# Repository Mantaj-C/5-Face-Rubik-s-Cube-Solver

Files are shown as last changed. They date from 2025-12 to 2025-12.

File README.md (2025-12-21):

# 🤖 Rubik’s Cube Solver – 5-Face Camera System
### 🔗 LinkedIn Post  
I also shared this project on LinkedIn — read the full post here:  
👉 [LinkedIn](https://www.linkedin.com/posts/mantaj-chauhan-951b401b5_just-completed-my-custom-5-face-rubik-activity-7408614489727696896-skUq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)

This project is a custom Rubik’s Cube solving machine, fully designed from scratch on the hardware, control logic, UI, and computer vision side, and powered by the well-known [rob-twophase](https://github.com/efrantar/rob-twophase) solving algorithm to improve my skills in:

- C++ software architecture  
- OpenCV computer vision  
- SolidWorks mechanical design  
- PCB design in Altium  
- Stepper motor control  
- TCP/IP networking  

The system uses a **client–server architecture**:

- 🍓 **Raspberry Pi → Client**  
  Handles motors, microstepping, camera capture, OpenCV color detection.

- 💻 **MacBook → Server**  
  Handles solving, graphical interface, 3D cube rendering, and control panel.

---

## 🎥 Demo Videos

**System Demo:**  
https://youtu.be/CzUOWeb3go8  

**SolidWorks Breakdown:**  
https://youtu.be/Gd5gCoYmTEs  

---

## 📂 Project Structure
```text
RubiksCubeSolver/
│
├── PCB Files/            # Custom PCB schematics + motor driver board
│
├── Solidworks Files/     # Full CAD of the solver mechanism
│
└── Src/
    ├── Client/           # Raspberry Pi: motor control + camera scanning
    └── Server/           # Mac: solver engine, UI, 3D viewer (SFML + OpenGL)
```

---

# 🏗 System Overview

## 💻 Server (Mac)
Responsible for:
- Running the [**rob-twophase**](https://github.com/efrantar/rob-twophase) solver  
- Managing the **SFML + OpenGL** graphical control panel  
- Rendering a **3D cube** with animations  
- Sending commands to the Pi  
- Parsing responses  
- Timing, batching moves, and UI updates  

Technologies used:
- C++20  
- SFML  
- OpenGL  
- TCP/IP sockets  

---

## 🍓 Client (Raspberry Pi)
Responsible for:
- Driving 6 stepper motors  
- Applying microstepping (Full → Sixteenth)  
- Handling acceleration & deceleration curves  
- Capturing images with OpenCV  
- Detecting colors with HSV processing  
- Validating cube color layout  
- Sending the final **54-character facelet string** to the server  

Technologies used:
- C++  
- OpenCV  
- pigpio  
- Multithreading  
- TCP/IP sockets  

---

# 🌐 TCP/IP Communication

The architecture uses a **simple text-based custom protocol** over TCP sockets.

## Server → Client Commands
```text
B M <face> <direction> <angle>;    # Rotate face
B F <freq>;                        # Set stepper frequency
B S;                               # Start sync (camera scan)
B T;                               # Start solve timer
Q                                  # Quit
```
## Client → Server Responses
```text
T <time_ms>          # Solve time in milliseconds
S <54-char-facelet>  # Camera-detected cube state
DONE                 # No special condition
```

---

# ⭐ Key Features

### 🖼 5-Face Camera Scanning
- Captures 13 images  
- Uses polygon masks to isolate facelets  
- Computes average HSV color  
- Maps HSV ranges → Rubik’s cube colors  
- Performs cube validity checks  

### ⚙️ Stepper Motor System
- Custom acceleration/deceleration curve  
- Shared microstepping modes  
- Ring-gear stepper for cube rotation  
- 5 turning steppers for each face  
- PWM + GPIO control via pigpio  

### 🧠 Solving Logic
- Uses [**rob-twophase**](https://github.com/efrantar/rob-twophase) solver  
- Converts solver moves → motor moves  
- Supports patterns, shuffles, syncing  

### 🖥 Graphical UI
- Built with **SFML + OpenGL**  
- Real-time visual cube  
- Move animations  
- Pattern selection  
- Manual motor controls  
- Timers & solve history  

### 🛠 Mechanical + PCB Design
- Entirely designed in SolidWorks  
- Custom PCB designed in Altium for stepper drivers  
- Gear system + mounting structure  
- Designed for stability, alignment, and lighting  

---

# 📘 What I Learned

This project helped me grow in:

- C++ class design, multithreading, and architecture  
- Real-time image processing with OpenCV  
- Hardware–software integration  
- Stepper motor tuning and microstepping  
- TCP/IP networking and protocol design  
- SFML & OpenGL graphics  
- SolidWorks mechanical design  
- Altium PCB layout and driver electronics  
- Full system debugging across multiple platforms  

This was one of my most complete end-to-end engineering builds, combining software, mechanical, electrical, and computer vision into a single cohesive system.

The solver is powered by the [rob-twophase] library.

[rob-twophase]: https://github.com/efrantar/rob-twophase

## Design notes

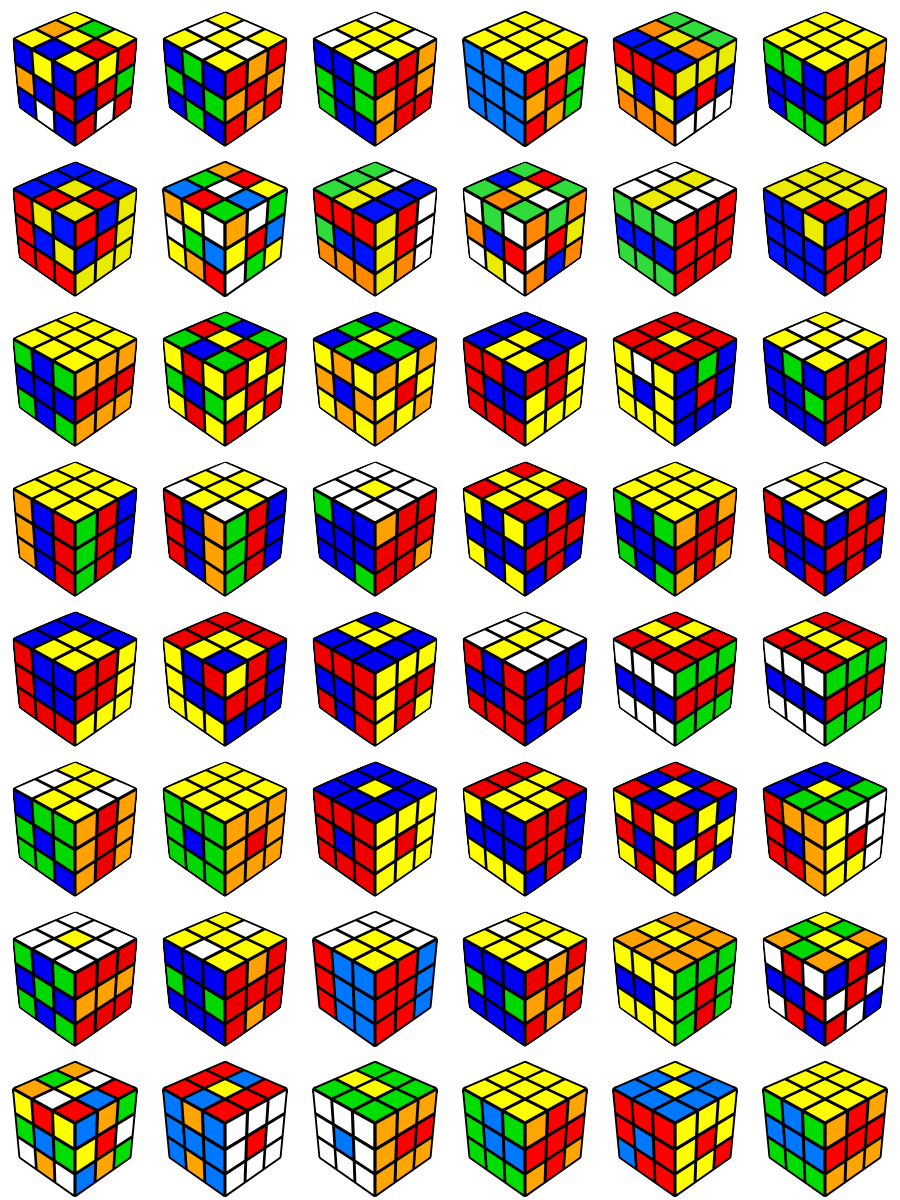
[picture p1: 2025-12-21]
Src/Client/Patterns_Sprite_Sheet.png

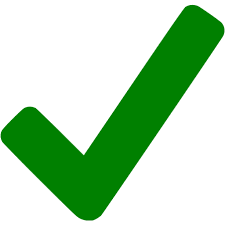
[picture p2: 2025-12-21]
Src/Client/check.png

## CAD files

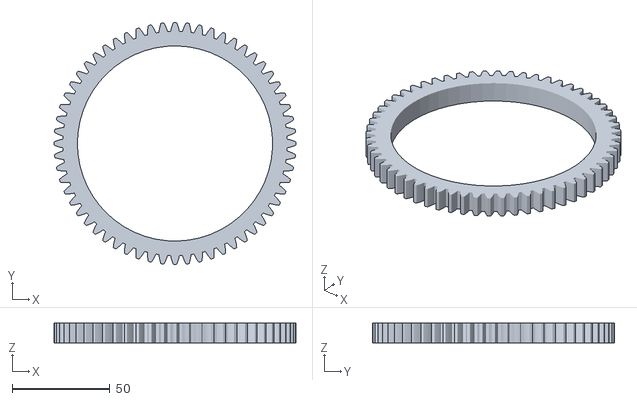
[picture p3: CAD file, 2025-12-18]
Solidworks Files/Ring_Gear.STL
124.0 x 124.0 x 10.0

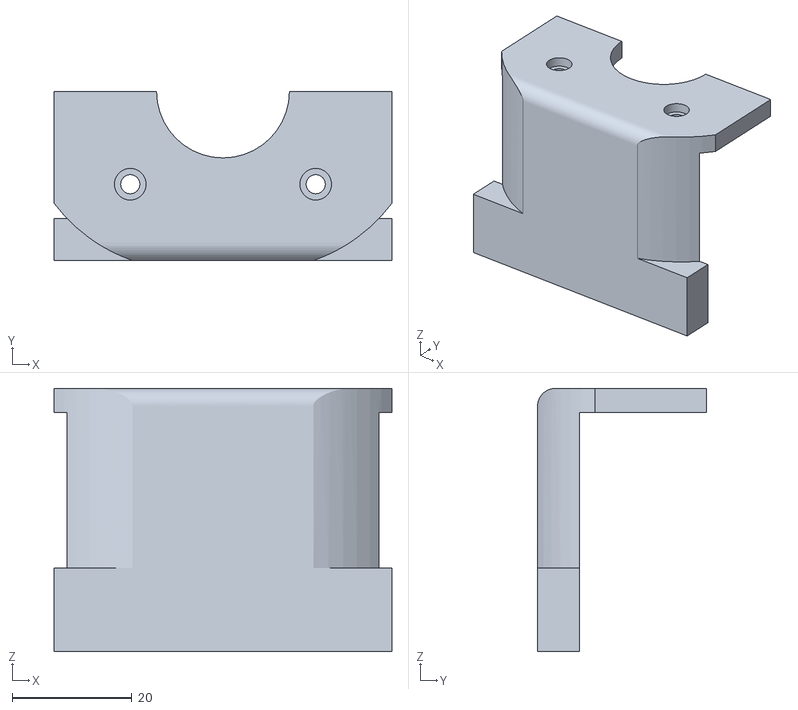
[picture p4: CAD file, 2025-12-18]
Solidworks Files/Middle_Stepper_Bracket.STL
56.5 x 28.2 x 44.0

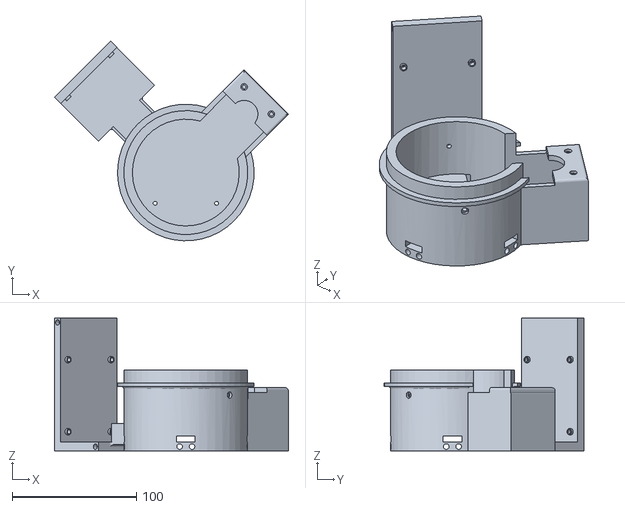
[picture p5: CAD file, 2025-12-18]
Solidworks Files/Base.STL
188.4 x 160.8 x 107.0

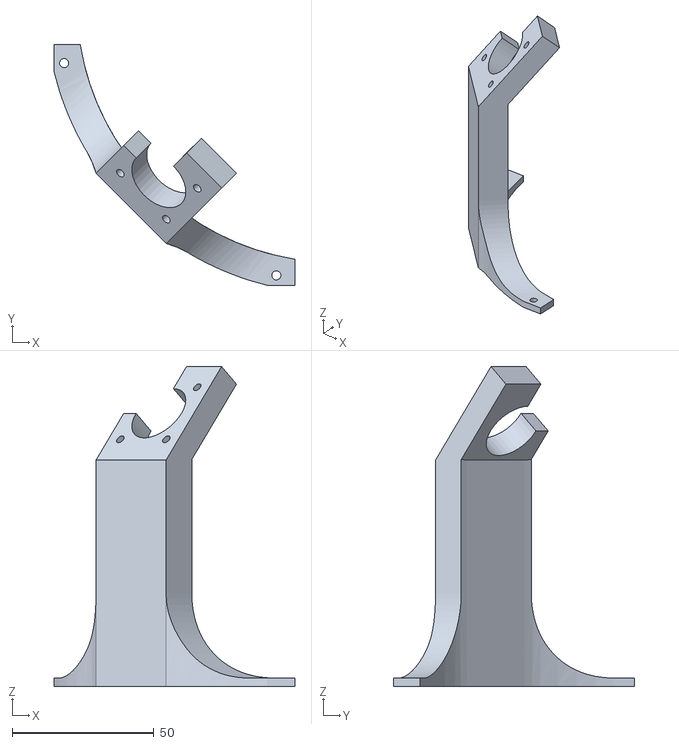
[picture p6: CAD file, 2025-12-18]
Solidworks Files/Camera_Mount.STL
85.0 x 85.0 x 113.1

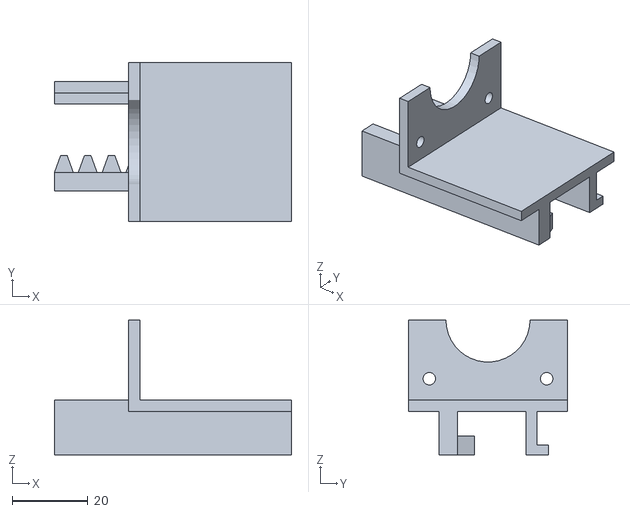
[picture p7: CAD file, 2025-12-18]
Solidworks Files/Stepper_Racks.STL
62.6 x 42.0 x 35.6

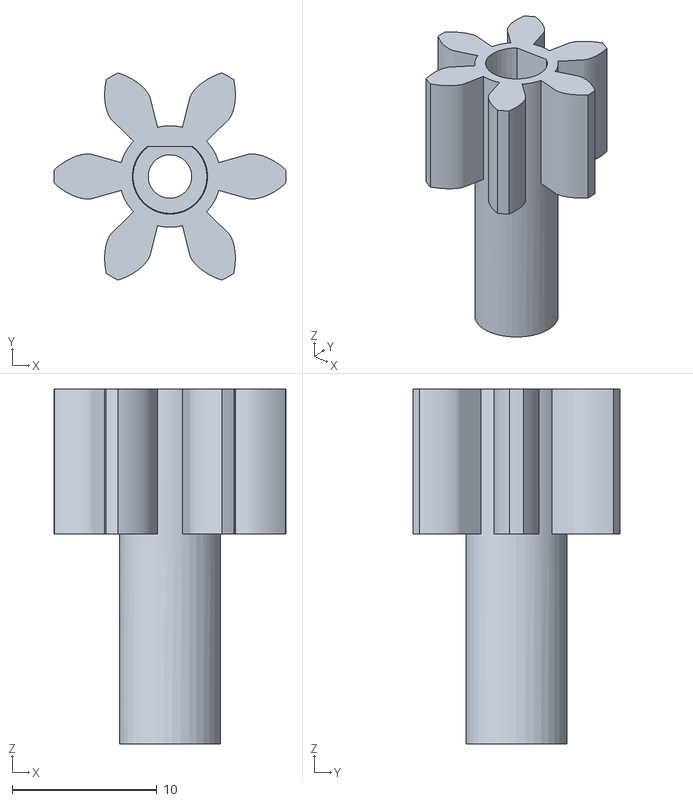
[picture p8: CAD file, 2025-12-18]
Solidworks Files/Stepper_Gear.STL
16.0 x 14.3 x 24.5

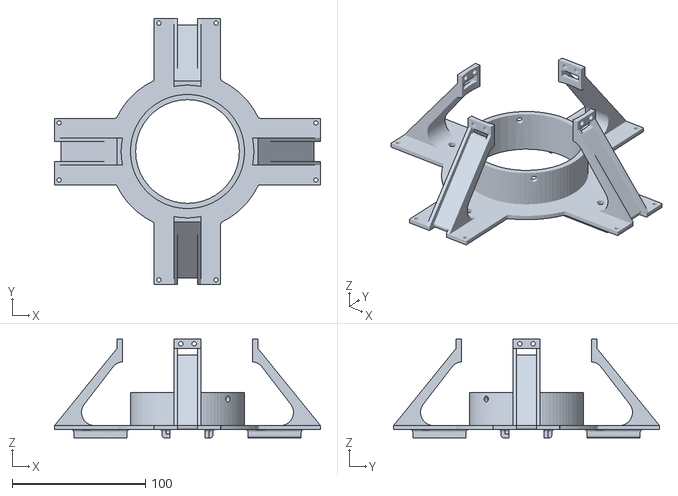
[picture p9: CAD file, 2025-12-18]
Solidworks Files/Upper_Level.STL
200.0 x 200.0 x 74.2

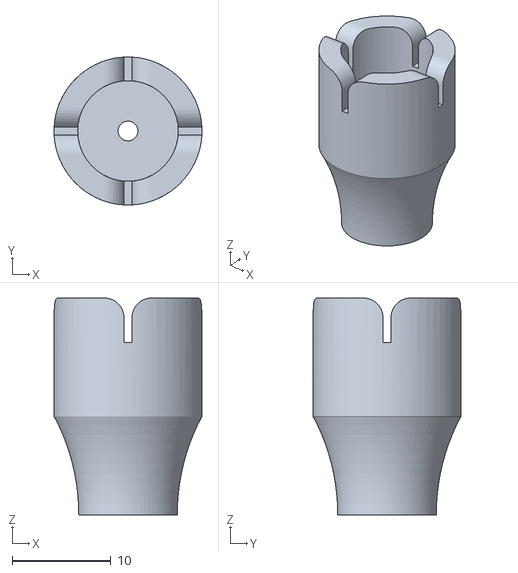
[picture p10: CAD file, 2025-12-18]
Solidworks Files/Stepper_To_Cube_Connection.STL
15.0 x 15.0 x 22.0

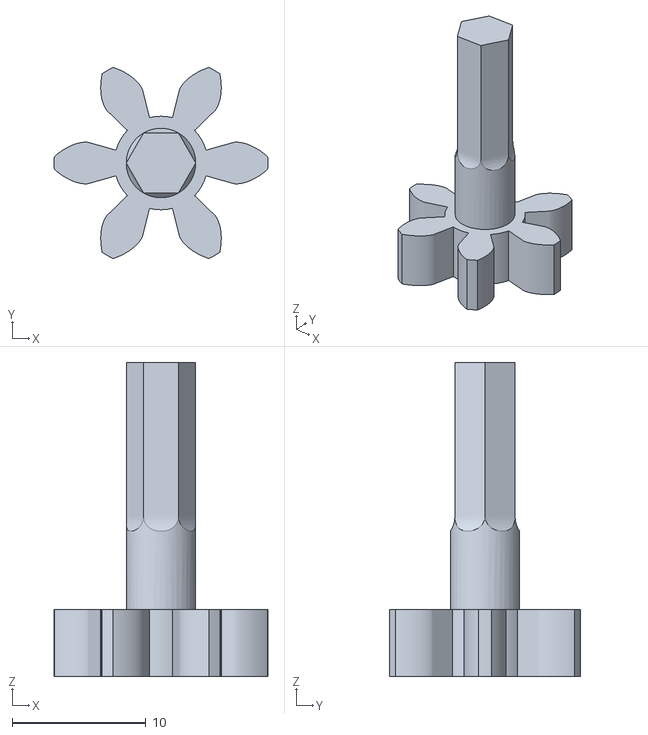
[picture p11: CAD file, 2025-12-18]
Solidworks Files/Ring_to_Stepper_Gear_1.STL
16.0 x 14.3 x 23.5

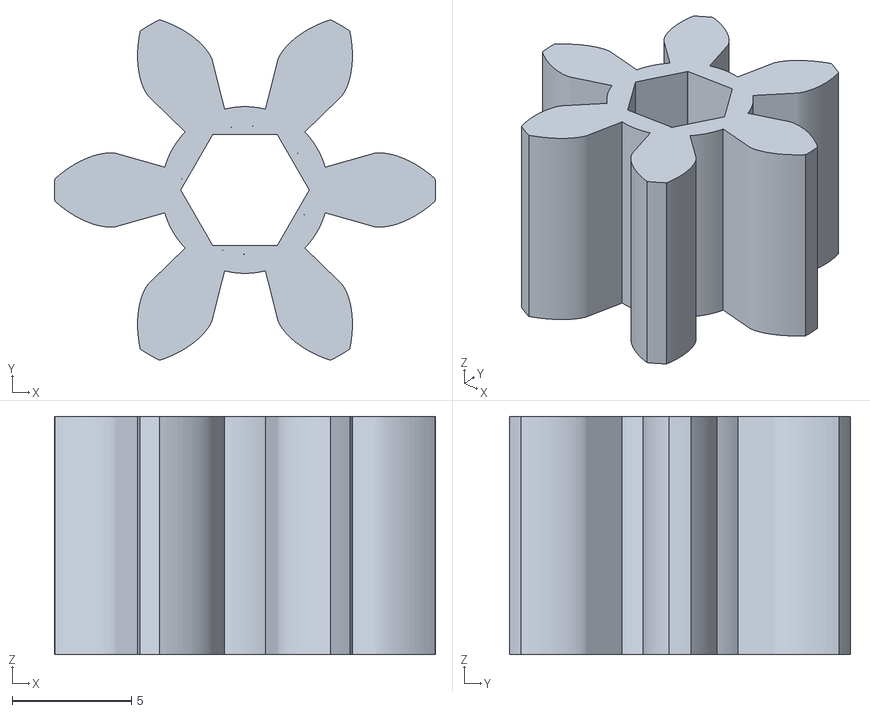
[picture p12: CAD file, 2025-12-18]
Solidworks Files/Ring_to_Stepper_Gear_2.STL
16.0 x 14.3 x 10.0

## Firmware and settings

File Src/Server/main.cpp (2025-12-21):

#include "GPIO.h"
#include "Stepper.h"
#include "Camera.h"
#include <arpa/inet.h>
#include <netinet/in.h>
#include <sys/socket.h>
#include <unistd.h>
#include <cstring>
#include <iostream>
#include <sstream>
#include <thread>
#include <vector>
#include <chrono>

// ---------------------- Pin Definitions ----------------------
// Ring gear stepper (locks/unlocks the cube clamp)
#define RING_Gear_Stepper_Enable_Pin     24
#define RING_Gear_Stepper_Direction_Pin  19
#define RING_Gear_Stepper_Step_Pin       26
#define RING_Gear_Stepper_MS1_Pin        25
#define RING_Gear_Stepper_MS2_Pin        8
#define RING_Gear_Stepper_MS3_Pin        7

// Shared microstepping pins for all turning steppers
#define Turning_Steppers_Enable_Pin      23
#define Turning_Steppers_MS1_Pin         16
#define Turning_Steppers_MS2_Pin         20
#define Turning_Steppers_MS3_Pin         21

// Individual face steppers (Bottom, North, East, South, West)
#define Bottom_Stepper_Direction_Pin     27
#define Bottom_Stepper_Step_Pin          22

#define North_Stepper_Direction_Pin      4
#define North_Stepper_Step_Pin           17

#define East_Stepper_Direction_Pin       9
#define East_Stepper_Step_Pin            10

#define South_Stepper_Direction_Pin      6
#define South_Stepper_Step_Pin           13

#define West_Stepper_Direction_Pin       11
#define West_Stepper_Step_Pin            5

// ------------------- Server / Motion Constants ----------------
#define DEFAULT_FREQUENCY 1350          // Default step pulse frequency (Hz)
#define PORT 5050                       // TCP port
#define BUFFER_SIZE 1024
#define RING_STEPPER_LOCK_DEGREES 800   // Steps for locking/unlocking clamp

// #define CAMERA_STREAM                 // Enable live camera preview
// #define NO_CLIENT_TESTING             // Enable local stdin command mode

int main() {
    // ---- Camera object ----
    Camera cam;

#ifdef CAMERA_STREAM
    // Optional: start asynchronous camera preview for calibration/debug
    std::thread t(std::bind(&Camera::getandshow, &cam));
    t.detach();
#endif

    int default_freq = DEFAULT_FREQUENCY;

    // Timer / sync state flags
    float solve_time = 0;
    bool timer_flag = false;
    bool sync_flag = false;
    bool valid_cube = true;

    auto start = std::chrono::high_resolution_clock::now();

    // Shared microstepping mode for all face steppers
    Stepper::StepMode sharedMode = Stepper::FULL;

    // ---------------------- Stepper Initialization ----------------------
    // Ring gear stepper (lock/unlock)
    Stepper Gear_Stepper(
        RING_Gear_Stepper_Enable_Pin,
        RING_Gear_Stepper_Direction_Pin,
        RING_Gear_Stepper_Step_Pin,
        RING_Gear_Stepper_MS1_Pin,
        RING_Gear_Stepper_MS2_Pin,
        RING_Gear_Stepper_MS3_Pin
    );

    // Face steppers (all share same enable + MS1/MS2/MS3)
    Stepper Bottom_Stepper(
        Turning_Steppers_Enable_Pin,
        Bottom_Stepper_Direction_Pin,
        Bottom_Stepper_Step_Pin,
        Turning_Steppers_MS1_Pin,
        Turning_Steppers_MS2_Pin,
        Turning_Steppers_MS3_Pin,
        &sharedMode
    );

    Stepper North_Stepper(
        Turning_Steppers_Enable_Pin,
        North_Stepper_Direction_Pin,
        North_Stepper_Step_Pin,
        Turning_Steppers_MS1_Pin,
        Turning_Steppers_MS2_Pin,
        Turning_Steppers_MS3_Pin,
        &sharedMode
    );

    Stepper East_Stepper(
        Turning_Steppers_Enable_Pin,
        East_Stepper_Direction_Pin,
        East_Stepper_Step_Pin,
        Turning_Steppers_MS1_Pin,
        Turning_Steppers_MS2_Pin,
        Turning_Steppers_MS3_Pin,
        &sharedMode
    );

    Stepper South_Stepper(
        Turning_Steppers_Enable_Pin,
        South_Stepper_Direction_Pin,
        South_Stepper_Step_Pin,
        Turning_Steppers_MS1_Pin,
        Turning_Steppers_MS2_Pin,
        Turning_Steppers_MS3_Pin,
        &sharedMode
    );

    Stepper West_Stepper(
        Turning_Steppers_Enable_Pin,
        West_Stepper_Direction_Pin,
        West_Stepper_Step_Pin,
        Turning_Steppers_MS1_Pin,
        Turning_Steppers_MS2_Pin,
        Turning_Steppers_MS3_Pin,
        &sharedMode
    );

    // Index mapping for "face" integer in commands (0..5)
    // 0=Bottom, 1=East, 2=North, 3=Gear, 4=West, 5=South
    std::vector<Stepper> steppers = {
        Bottom_Stepper,
        East_Stepper,
        North_Stepper,
        Gear_Stepper,
        West_Stepper,
        South_Stepper
    };

    // ---------------------- TCP Server Setup ----------------------
    int server_fd = socket(AF_INET, SOCK_STREAM, 0);
    if (server_fd == -1) {
        perror("Socket creation failed");
        return 1;
    }

    sockaddr_in address{};
    address.sin_family = AF_INET;
    address.sin_addr.s_addr = INADDR_ANY;   // Bind on all interfaces
    address.sin_port = htons(PORT);

    if (bind(server_fd, (struct sockaddr*)&address, sizeof(address)) < 0) {
        perror("Bind failed");
        return 1;
    }

    if (listen(server_fd, 3) < 0) {
        perror("Listen failed");
        return 1;
    }

    std::cout << "Raspberry Pi motor server listening on port " << PORT << "...\n";

    // ---------------------- Main Accept Loop ----------------------
    while (true) {
#ifndef NO_CLIENT_TESTING
        // Wait for a client connection (Mac UI)
        int client_fd = accept(server_fd, nullptr, nullptr);
        if (client_fd < 0) {
            perror("Accept failed");
            continue;
        }
#endif

#ifdef NO_CLIENT_TESTING
        // Testing mode: no socket, just stdin
        int client_fd = 0;
#endif

        // -------------- Per-Client Command Loop --------------
        while (true) {

#ifdef NO_CLIENT_TESTING
            // Testing mode: read command from terminal
            std::string command;
            std::cout << "Enter command: ";
            std::getline(std::cin, command);
#endif

#ifndef NO_CLIENT_TESTING
            // Normal mode: read command from TCP socket
            char buffer[BUFFER_SIZE] = {0};
            int bytes_read = read(client_fd, buffer, BUFFER_SIZE);
            if (bytes_read <= 0) break;   // client disconnected
            std::string command(buffer, bytes_read);
#endif

            std::ostringstream reply;
            std::cout << "Received command: " << command << std::endl;

            // ---------------- BATCH COMMAND MODE ("B ...") ----------------
            if (command[0] == 'B') {
                // After 'B', we expect semicolon-separated mini-commands
                std::string sub = command.substr(1);
                std::istringstream batch(sub);
                std::string token;

                while (std::getline(batch, token, ';')) {
                    std::istringstream cmd(token);
                    std::string keyword;
                    cmd >> keyword;

                    // ---- M = Move: "M face direction amount" ----
                    if (keyword == "M") {
                        int face, direction, amount;
                        cmd >> face >> direction >> amount;

                        if (face >= 0 && face < (int)steppers.size()) {
                            auto dir = (direction == 1)
                                ? Stepper::CLOCKWISE
                                : Stepper::COUNTER_CLOCKWISE;

                            steppers[face].rotate(amount, dir, default_freq);

                            std::cout << "Rotated " << amount
                                      << " steps on face " << face
                                      << " in direction " << direction << std::endl;
                            // Optional delay here if needed for camera stability
                            // std::this_thread::sleep_for(std::chrono::milliseconds(1000));
                        }

                    // ---- E = Enable: "E face" ----
                    } else if (keyword == "E") {
                        int face;
                        cmd >> face;
                        if (face >= 0 && face < (int)steppers.size()) {
                            steppers[face].enable();
                        }

                    // ---- D = Disable: "D face" ----
                    } else if (keyword == "D") {
                        int face;
                        cmd >> face;
                        if (face >= 0 && face < (int)steppers.size()) {
                            steppers[face].disable();
                        }

                    // ---- F = Set Frequency: "F freq" ----
                    } else if (keyword == "F") {
                        int freq;
                        cmd >> freq;
                        default_freq = freq;

                    // ---- T = Timer Start ----
                    // Mac expects a "T <ms>" response when solving completes.
                    } else if (keyword == "T") {
                        timer_flag = true;
                        start = std::chrono::high_resolution_clock::now();

                    // ---- MS = Microstepping: "MS<group> <mode>" ----
                    // Example: "MS0 4" → group 0 (ring), SIXTEENTH mode
                    } else if (token.substr(0, 2) == "MS") {
                        int group, mode;
                        std::istringstream ms_cmd(token.substr(2));
                        ms_cmd >> group >> mode;

                        Stepper::StepMode sm;
                        switch (mode) {
                            case 0: sm = Stepper::FULL;      break;
                            case 1: sm = Stepper::HALF;      break;
                            case 2: sm = Stepper::QUARTER;   break;
                            case 3: sm = Stepper::EIGHTH;    break;
                            case 4: sm = Stepper::SIXTEENTH; break;
                            default:
                                std::cerr << "Invalid step mode: " << mode << std::endl;
                                send(client_fd, "ERR\n", 4, 0);
                                continue;
                        }

                        // group 0 = Gear stepper, group 1 = other steppers
                        if (group == 0) Gear_Stepper.setMode(sm);
                        else Bottom_Stepper.setMode(sm);

                    // ---- S = Sync (Full cube scan + color recognition) ----
                    } else if (keyword == "S") {
                        // Only run once per command; valid_cube forces exit
                        while (valid_cube) {
                            cam.sync_reset();

                            // Capture 13 images with specific rotation sequence
                            cam.getimage(0);

                            North_Stepper.rotate(90, Stepper::CLOCKWISE, default_freq / 2);
                            cam.getimage(1);

                            North_Stepper.rotate(90, Stepper::CLOCKWISE, default_freq / 2);
                            cam.getimage(2);

                            North_Stepper.rotate(90, Stepper::CLOCKWISE, default_freq / 2);
                            cam.getimage(3);

                            North_Stepper.rotate(90, Stepper::CLOCKWISE, default_freq / 2);

                            West_Stepper.rotate(90, Stepper::CLOCKWISE, default_freq / 2);
                            cam.getimage(4);

                            West_Stepper.rotate(90, Stepper::CLOCKWISE, default_freq / 2);
                            cam.getimage(5);

                            West_Stepper.rotate(90, Stepper::CLOCKWISE, default_freq / 2);
                            cam.getimage(6);

                            West_Stepper.rotate(90, Stepper::CLOCKWISE, default_freq / 2);

                            South_Stepper.rotate(90, Stepper::CLOCKWISE, default_freq / 2);
                            West_Stepper.rotate(180, Stepper::CLOCKWISE, default_freq / 2);
                            cam.getimage(7);

                            West_Stepper.rotate(180, Stepper::CLOCKWISE, default_freq / 2);
                            South_Stepper.rotate(90, Stepper::CLOCKWISE, default_freq / 2);
                            West_Stepper.rotate(180, Stepper::CLOCKWISE, default_freq / 2);
                            cam.getimage(8);

                            West_Stepper.rotate(180, Stepper::CLOCKWISE, default_freq / 2);
                            South_Stepper.rotate(90, Stepper::CLOCKWISE, default_freq / 2);
                            West_Stepper.rotate(180, Stepper::CLOCKWISE, default_freq / 2);
                            cam.getimage(9);

                            West_Stepper.rotate(180, Stepper::CLOCKWISE, default_freq / 2);
                            South_Stepper.rotate(90, Stepper::CLOCKWISE, default_freq / 2);

                            East_Stepper.rotate(90, Stepper::CLOCKWISE, default_freq / 2);
                            North_Stepper.rotate(180, Stepper::CLOCKWISE, default_freq / 2);
                            cam.getimage(10);

                            North_Stepper.rotate(180, Stepper::CLOCKWISE, default_freq / 2);
                            East_Stepper.rotate(90, Stepper::CLOCKWISE, default_freq / 2);
                            North_Stepper.rotate(180, Stepper::CLOCKWISE, default_freq / 2);
                            cam.getimage(11);

                            North_Stepper.rotate(180, Stepper::CLOCKWISE, default_freq / 2);
                            East_Stepper.rotate(90, Stepper::CLOCKWISE, default_freq / 2);
                            North_Stepper.rotate(180, Stepper::CLOCKWISE, default_freq / 2);
                            cam.getimage(12);

                            North_Stepper.rotate(180, Stepper::CLOCKWISE, default_freq / 2);
                            East_Stepper.rotate(90, Stepper::CLOCKWISE, default_freq / 2);

                            valid_cube = false;

                            // Run classification + validity check
                            bool temp = cam.sync();
                            //valid_cube = !cam.sync(); // optional loop retry
                            sync_flag = true;
                        }

                    // ---- L = Lock clamp (Ring gear forward) ----
                    } else if (keyword == "L") {
                        Gear_Stepper.rotate(RING_STEPPER_LOCK_DEGREES,
                                            Stepper::CLOCKWISE,
                                            default_freq);

                    // ---- U = Unlock clamp (Ring gear backward) ----
                    } else if (keyword == "U") {
                        Gear_Stepper.rotate(RING_STEPPER_LOCK_DEGREES,
                                            Stepper::COUNTER_CLOCKWISE,
                                            default_freq);

                    // ---- P = Increase frequency ----
                    } else if (keyword == "P") {
                        default_freq += 10;
                        std::cout << "Changed frequency to " << default_freq << std::endl;

                    // ---- G = Decrease frequency ----
                    } else if (keyword == "G") {
                        default_freq -= 10;
                        std::cout << "Changed frequency to " << default_freq << std::endl;

                    } else {
                        // Unknown keyword inside batch
                        reply << "ERR\n";
                    }
                }

                // ---- Reply selection after batch ----

                if (timer_flag) {
                    // End timing, send solve time
                    timer_flag = false;
                    auto end = std::chrono::high_resolution_clock::now();
                    std::chrono::duration<double, std::milli> elapsed = end - start;
                    solve_time = elapsed.count();
                    reply << "T " << solve_time << "\n";
                } else if (sync_flag) {
                    // Send sync result (facelet string)
                    sync_flag = false;
                    valid_cube = true;

                    std::string facelet = cam.getfacelet();
                    reply << "S " << facelet << "\n";
                } else {
                    // Default: batch processed
                    reply << "DONE\n";
                }

            // ---------------- SINGLE-CHAR COMMANDS (Not in batch) ----------------
            } else {
                if (command[0] == 'Q') {
                    // Quit command from client
                    reply << "BYE\n";
                    send(client_fd, reply.str().c_str(), reply.str().size(), 0);
                    break;
                } else {
                    reply << "ERR\n";
                }
            }

            // Send accumulated reply back to client
            std::string response = reply.str();
            send(client_fd, response.c_str(), response.size(), 0);
        }

        // Client connection closed
        close(client_fd);
    }

    // Should never reach here in normal daemon mode
    close(server_fd);
    return 0;
}

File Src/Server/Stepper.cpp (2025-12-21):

#include "Stepper.h"

/* ------------------------------------------------------------
   Constructor
   - Initializes a stepper motor with:
       - Enable pin
       - Direction pin
       - Step pin
       - Microstepping control pins (MS1, MS2, MS3)
   - Can share a microstepping mode via sharedMode pointer
   - Sets initial direction and enables the driver
   ------------------------------------------------------------ */
Stepper::Stepper(int enable_pin, int dir, int step,
                 int MS1, int MS2, int MS3,
                 StepMode* sharedMode,
                 StepDirection direction)
    : gpio(GPIO::getInstance()),
      enable_pin(enable_pin),
      direction_pin(dir),
      step_pin(step),
      MS1(MS1),
      MS2(MS2),
      MS3(MS3),
      shared_mode_ptr(sharedMode),
      local_mode(FULL),
      direction(direction),
      position(0.0f)
{
    // Enable the stepper driver by default
    enable();

    // Set initial direction pin
    gpio.write_digi(direction_pin, direction);

    // Apply microstepping mode (either shared or local)
    applyMode();
}

Stepper::~Stepper() {}

/* ------------------------------------------------------------
   setMode(mode)
   - Sets the step mode for this motor
   - If a shared_mode_ptr is provided, it writes into the shared
     mode (used by multiple steppers).
   - Otherwise, it uses this motor's local_mode.
   - Then calls applyMode() to update MS1/MS2/MS3.
   ------------------------------------------------------------ */
void Stepper::setMode(StepMode mode) {
    if (shared_mode_ptr) {
        *shared_mode_ptr = mode;
    } else {
        local_mode = mode;
    }
    applyMode();
}

/* ------------------------------------------------------------
   getMode()
   - Returns the currently active step mode:
       - Shared mode if shared_mode_ptr is set
       - Local mode otherwise
   ------------------------------------------------------------ */
Stepper::StepMode Stepper::getMode() const {
    return shared_mode_ptr ? *shared_mode_ptr : local_mode;
}

/* ------------------------------------------------------------
   applyMode()
   - Actually applies the microstepping mode to the MS1/MS2/MS3
     pins based on the current mode (FULL, HALF, etc).
   - Uses a lookup table to avoid repeated if/switch logic.
   ------------------------------------------------------------ */
void Stepper::applyMode() {
    StepMode mode = shared_mode_ptr ? *shared_mode_ptr : local_mode;

    // Lookup table: MS1, MS2, MS3 for each mode
    static const bool microstep_pins[][3] = {
        /* FULL      */ {false, false, false},
        /* HALF      */ {true,  false, false},
        /* QUARTER   */ {false, true,  false},
        /* EIGHTH    */ {true,  true,  false},
        /* SIXTEENTH */ {true,  true,  true}
    };

    const bool* config = microstep_pins[mode];

    // Write microstepping configuration to pins
    gpio.write_digi(MS1, config[0]);
    gpio.write_digi(MS2, config[1]);
    gpio.write_digi(MS3, config[2]);
}

/* ------------------------------------------------------------
   step(steps, direction, freq)
   - Low-level stepping function:
       - Handles direction changes
       - Applies a basic acceleration / deceleration profile
       - Tries to keep total move time ≈ (steps / freq) seconds
   - steps: number of step pulses
   - direction: CLOCKWISE or COUNTER_CLOCKWISE
   - freq: nominal step frequency (Hz)
   ------------------------------------------------------------ */
void Stepper::step(int steps, StepDirection direction, int freq) {
    // If direction changed (and this isn't the special 180 case),
    // update the direction pin and add a short settling delay.
    if (direction != this->direction && steps != 180) {
        gpio.write_digi(direction_pin, direction);
        this->direction = direction;
        gpioDelay(10000 * freq / 800);  // small dir-change delay
    }

    // Total allowed movement time in microseconds
    int total_time_us = 1e6 * steps / freq;

    // Simple acceleration profile:
    // 20% ramp-up + 60% cruise + 20% ramp-down
    int ramp_steps   = steps * 0.2;
    int cruise_steps = steps - 2 * ramp_steps;

    // Base delay between steps for target frequency
    double base_delay = 1e6 / freq;

    // Precompute all delays (per-step)
    std::vector<int> delays;
    delays.reserve(steps);

    // Acceleration: start slower, then speed up
    for (int i = 0; i < ramp_steps; ++i) {
        double scale = 1.0 - static_cast<double>(i) / ramp_steps; // 1 → 0
        delays.push_back(static_cast<int>(base_delay * (1.0 + scale * 0.5)));
    }

    // Cruise: constant speed
    for (int i = 0; i < cruise_steps; ++i) {
        delays.push_back(static_cast<int>(base_delay));
    }

    // Deceleration: slow down again
    for (int i = 0; i < ramp_steps; ++i) {
        double scale = static_cast<double>(i) / ramp_steps; // 0 → 1
        delays.push_back(static_cast<int>(base_delay * (1.0 + scale * 0.5)));
    }

    // Adjust delays to match desired total time as closely as possible
    int sum_delays = std::accumulate(delays.begin(), delays.end(), 0);
    double adjust_factor = static_cast<double>(total_time_us) / sum_delays;
    for (int& d : delays) {
        d = static_cast<int>(d * adjust_factor);
    }

    // Perform actual stepping based on computed delays
    for (int i = 0; i < steps; ++i) {
        gpio.write_digi(step_pin, true);
        gpioDelay(delays[i] / 2);
        gpio.write_digi(step_pin, false);
        gpioDelay(delays[i] / 2);
    }

    std::cout << "Done stepping " << steps << " steps" << std::endl;
}

/* ------------------------------------------------------------
   rotate(angle, direction, freq)
   - High-level function:
       - Converts a requested rotation angle into steps based on:
            - 200 steps per revolution (base)
            - Current microstepping mode
       - Delegates to step()
       - Tracks the logical "position" in degrees
   ------------------------------------------------------------ */
void Stepper::rotate(float angle, StepDirection direction, int freq) {
    int base_steps_per_rev = 200;  // standard 1.8°/step motor

    StepMode mode = shared_mode_ptr ? *shared_mode_ptr : local_mode;

    // Microstepping multiplier
    int multiplier = 1;
    switch (mode) {
        case FULL:      multiplier = 1;  break;
        case HALF:      multiplier = 2;  break;
        case QUARTER:   multiplier = 4;  break;
        case EIGHTH:    multiplier = 8;  break;
        case SIXTEENTH: multiplier = 16; break;
    }

    // Convert angle → steps
    float steps = (angle / 360.0f) * base_steps_per_rev * multiplier;

    // Execute motion
    step(static_cast<int>(steps), direction, freq);

    // Track logical angle (can be used for soft-limits or debugging)
    position += angle;
}
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

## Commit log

2025-12-18 Rename Solidworks Files/Ring to Stepper Gear/Ring_to_Stepper_Gear_1_V2.STL to Solidworks Files/Ring_to_Stepper_Gear_1_V2.STL
    [Ring_to_Stepper_Gear_1_V2.STL]
2025-12-18 Rename Solidworks Files/Ring to Stepper Gear/Ring_to_Stepper_Gear_2_V2.STL to Solidworks Files/Ring_to_Stepper_Gear_2_V2.STL
    [Ring_to_Stepper_Gear_2_V2.STL]
2025-12-21 Revise README for Rubik’s Cube Solver project
    Updated the README to provide detailed project information, including system architecture, key features, and technologies used.
2025-12-21 Enhance README with detailed PCB and solver info
    Updated descriptions for PCB design and solver references.
